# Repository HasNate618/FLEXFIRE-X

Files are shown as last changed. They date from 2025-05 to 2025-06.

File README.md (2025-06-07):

# ⚡ FLEXFIRE-X: EMG-Controlled Cyberware-Inspired Projectile System

A wearable, servo-powered arm attachment that extends and fires a spring-loaded projectile using EMG muscle signals—built to mimic the immersive cyberware experience of *Cyberpunk 2077*.

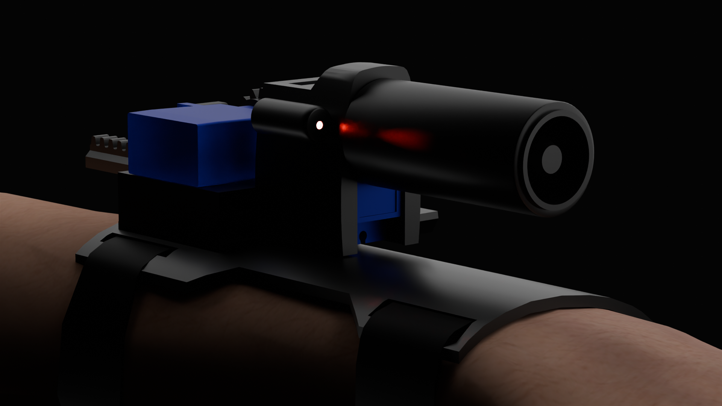
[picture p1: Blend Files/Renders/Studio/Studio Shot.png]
Studio Render


&nbsp;

## 🚀 Overview

**FLEXFIRE-X** is a bio-integrated device that mounts on the user's forearm and responds to intuitive muscle movements:

- ⬇️ **Wrist rotation** (palm down) → **Barrel extends**
- 💪 **Forearm flexion** → **Projectile fires**

This project explores how EMG signals can control physical actuators to feel like a seamless extension of the human body.

Demo Animation

&nbsp;

## 🎥 Video Demo

Watch FLEXFIRE-X in action:  
Watch the demo (https://youtube.com/shorts/VqzTay1VbeE)

> A quick demonstration of EMG-based extension and firing using wrist and forearm movements.

&nbsp;

## 🧠 Concept & Inspiration

Inspired by the **Projectile Launch System** from *Cyberpunk 2077*, this prototype brings sci-fi to life with:

- EMG-based gesture control
- A concealed-to-exposed transformation mechanism
- Arduino-powered spring-loaded projectile launch

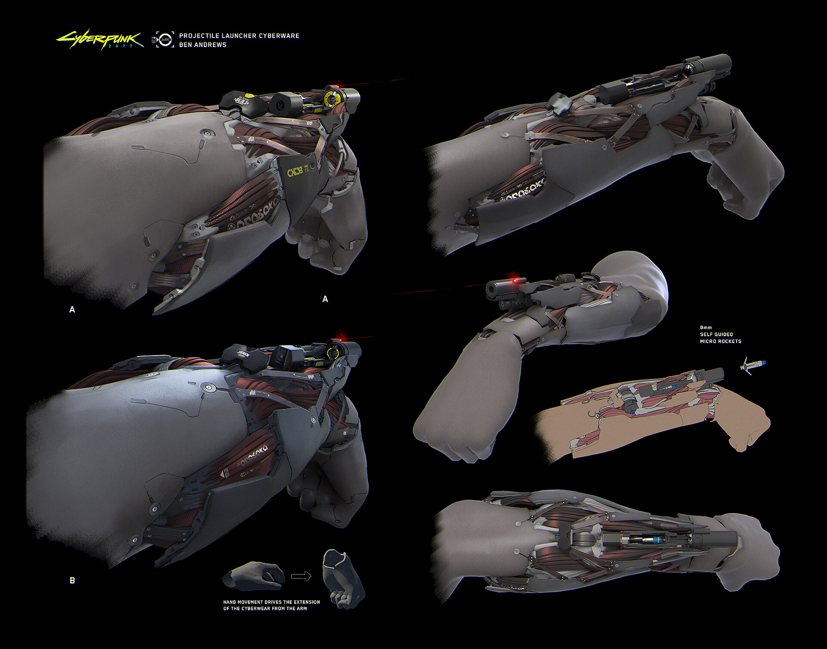
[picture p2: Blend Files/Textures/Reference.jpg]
Concept Art Reference

**Art by Ben Andrews on [ArtStation](https://www.artstation.com/artwork/WKqEVD)*

&nbsp;

## 💪 EMG Signal Detection
- Electrodes placed over the *flexor carpi radialis* muscle on the forearm help detect proper movement of the wrist and forearm flexion.
- Muscle signals are filtered via moving average to produce more stable results.
- Three flexion states are used for control based on the sensor readings:
  - **Low Flexion (<50)** → Barrel stays retracted
  - **Medium Flexion (>50)** → Barrel extends
  - **High Flexion (>500)** → Projectile is launched

&nbsp;

## 🔧 3D Design

The FLEXFIRE-X uses a total of nine 3D printed components that were designed in Blender and printed in PLA. 

An exploded view of the device shows the layout of each part:

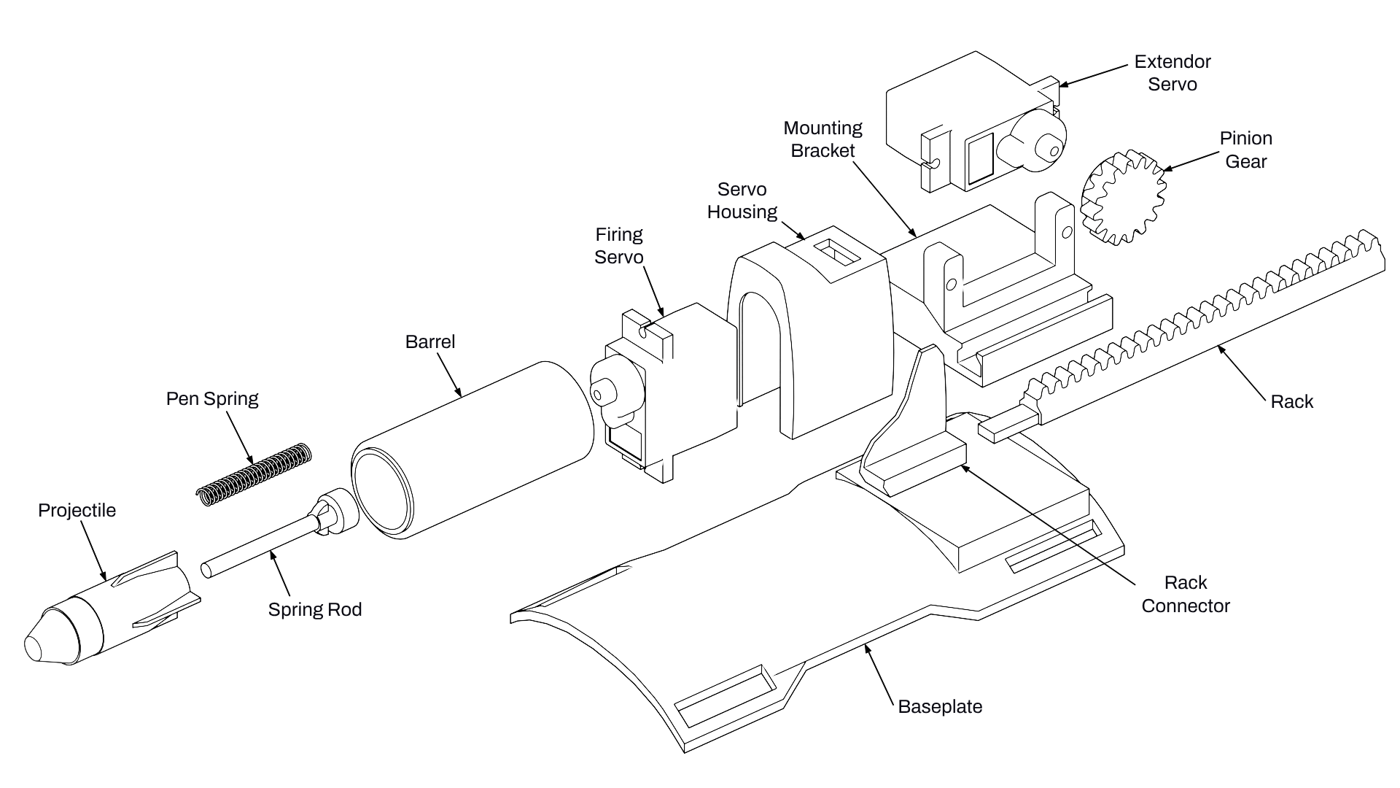
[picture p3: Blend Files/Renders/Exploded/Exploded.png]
Exploded View

**The Mounting Bracket, Rack and Pinion Gear were modified from [potentprintables](https://www.thingiverse.com/thing:3170748) design on Thingiverse*

&nbsp;

## 🔫 Launching Mechanism

The projectile is launched using a spring-loaded barrel system controlled by a servo-actuated locking mechanism. Here's how it works:

1. The rocket is inserted into the barrel, with its fins aligning with internal grooves to ensure proper orientation and constrain its rotation.
2. As the rocket is pushed in, the spring compresses, storing potential energy.
3. A servo rotates a locking rod, holding the rocket securely in place under spring tension.
4. When the servo rotates back to its original position, the lock is disengaged, allowing the spring to decompress and launch the rocket forward.
5. **Note:** To increase launch force, multiple springs can be nested concentrically within the barrel.

<p align="center">
  Launcher Demo
</p>

&nbsp;

## ⚙️ Hardware & Components

The following components were used to build the device and circuit

| Component | Purpose |
|---|---|
| Arduino Nano RP2040 Connect | Main microcontroller |
| EMG Sensor | Muscle signal detection |
| SG90 Servo Motor | Projectile launch trigger |
| Continuous Servo | Barrel extension/retraction |
| Pen Springs | Launches the projectile |
| 5V Red Laser | Aim assistance |
| 9V Batteries | On-body power management |

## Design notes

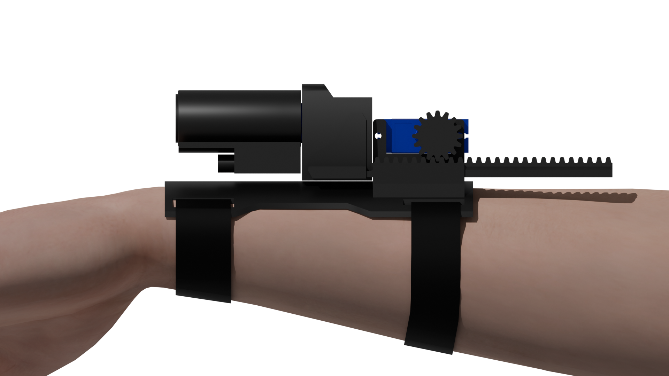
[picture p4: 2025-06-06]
Blend Files/Renders/Studio/Side_Transparent.png

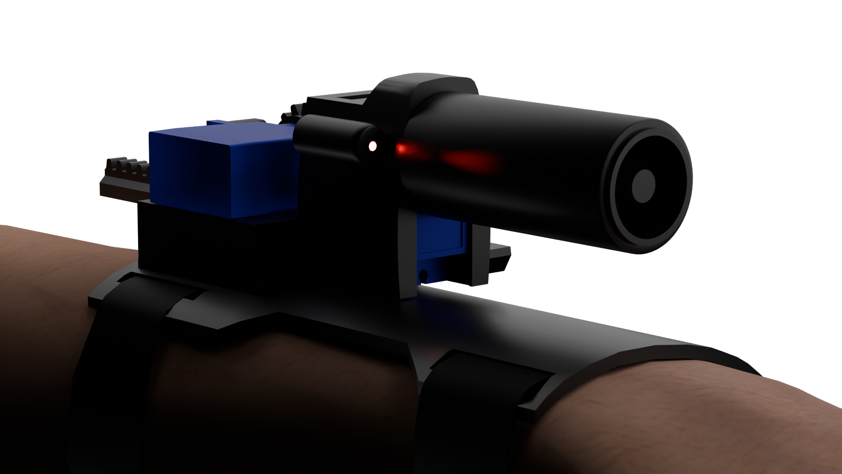
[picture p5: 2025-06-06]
Blend Files/Renders/Studio/Studio_Transparent.png

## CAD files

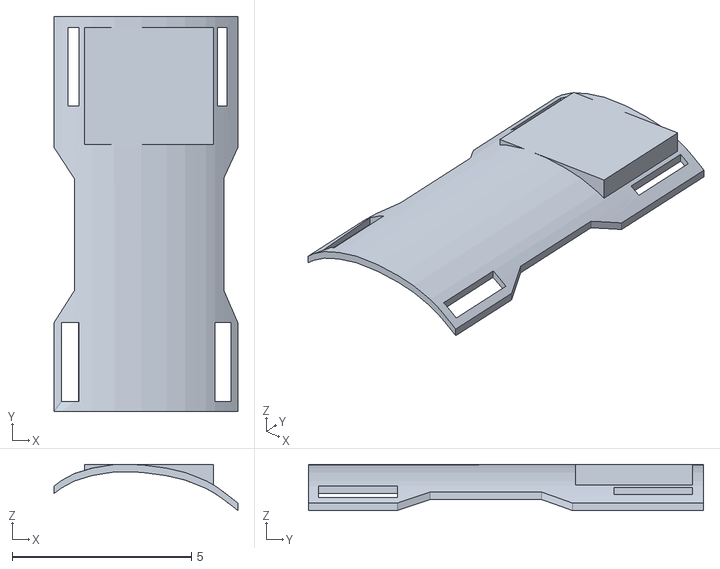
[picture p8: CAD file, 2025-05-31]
3D Print Files/Baseplate.stl
5.12 x 11.0 x 1.29

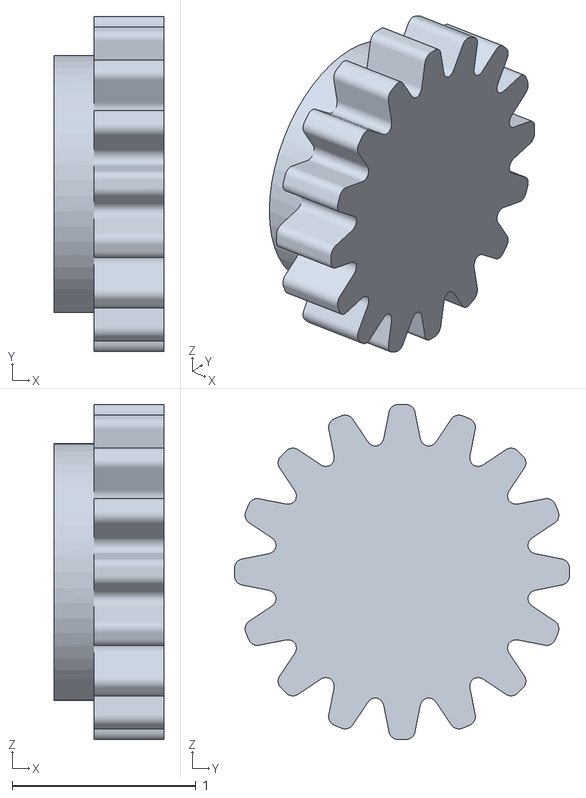
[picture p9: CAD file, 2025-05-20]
3D Print Files/Pinion Gear.stl
0.597 x 1.82 x 1.82

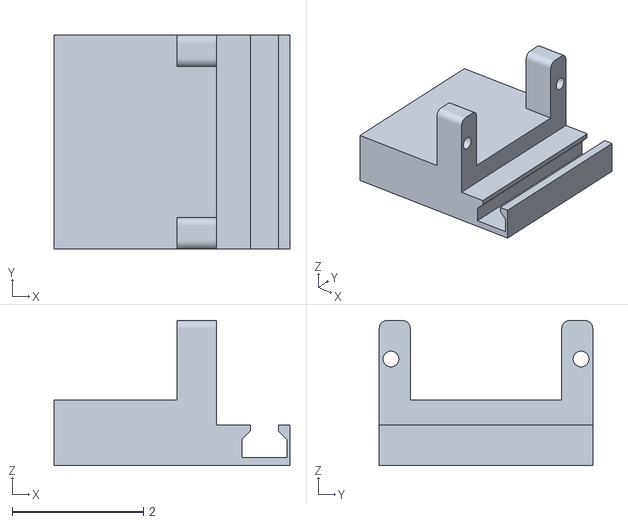
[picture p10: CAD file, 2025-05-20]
3D Print Files/Rack.stl
3.60 x 3.26 x 2.22

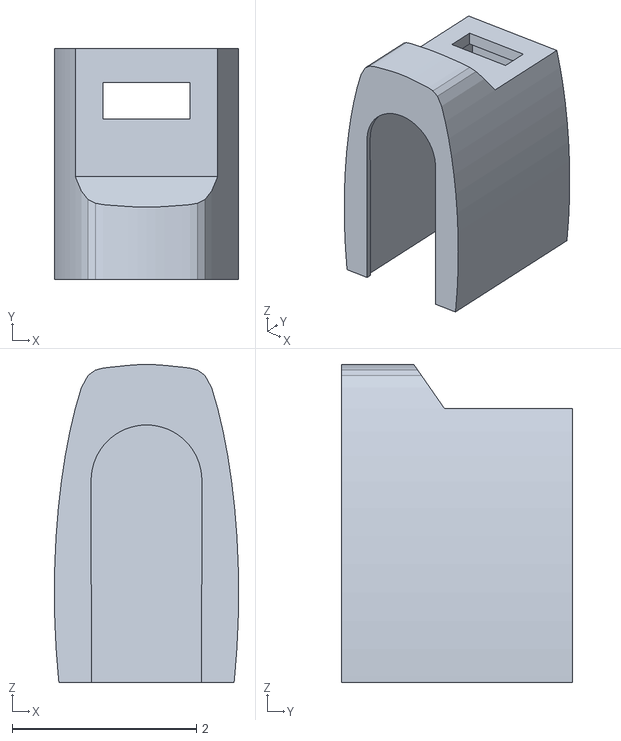
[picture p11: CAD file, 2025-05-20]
3D Print Files/Servo Housing.stl
2.00 x 2.50 x 3.45

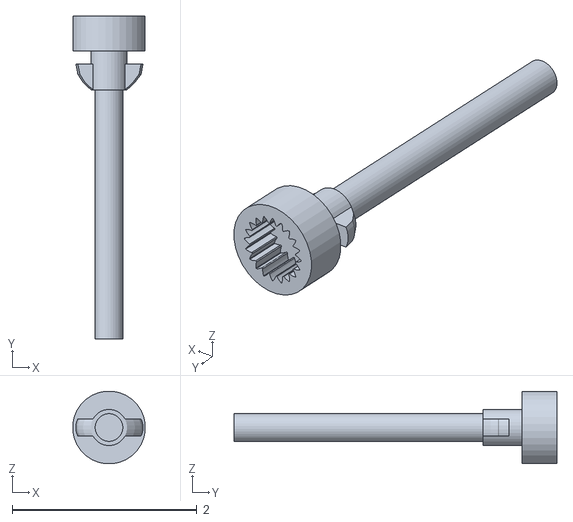
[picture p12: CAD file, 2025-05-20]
3D Print Files/Spring Rod.stl
0.785 x 3.50 x 0.785

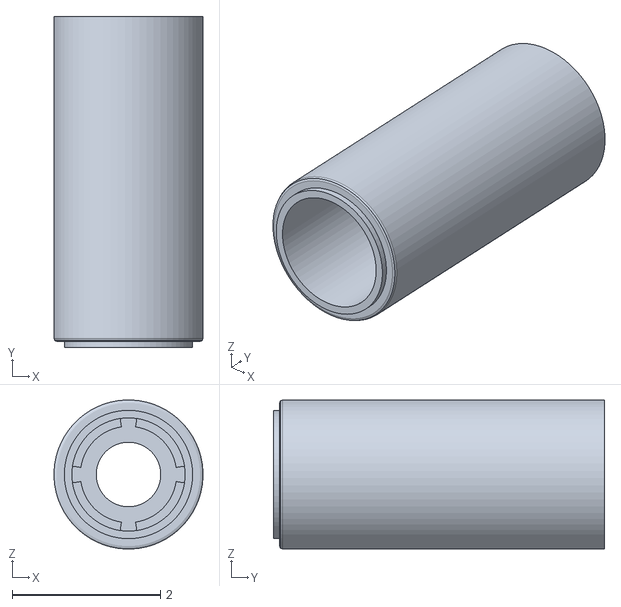
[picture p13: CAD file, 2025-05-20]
3D Print Files/Barrel.stl
2.01 x 4.48 x 2.01

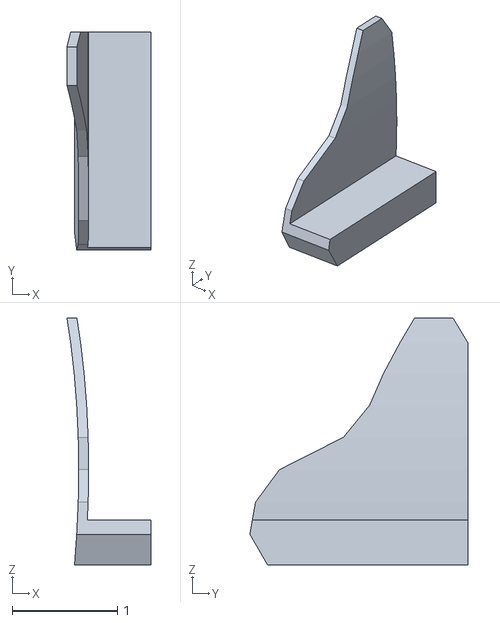
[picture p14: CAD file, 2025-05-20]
3D Print Files/Rack Connector.stl
0.8 x 2.08 x 2.35

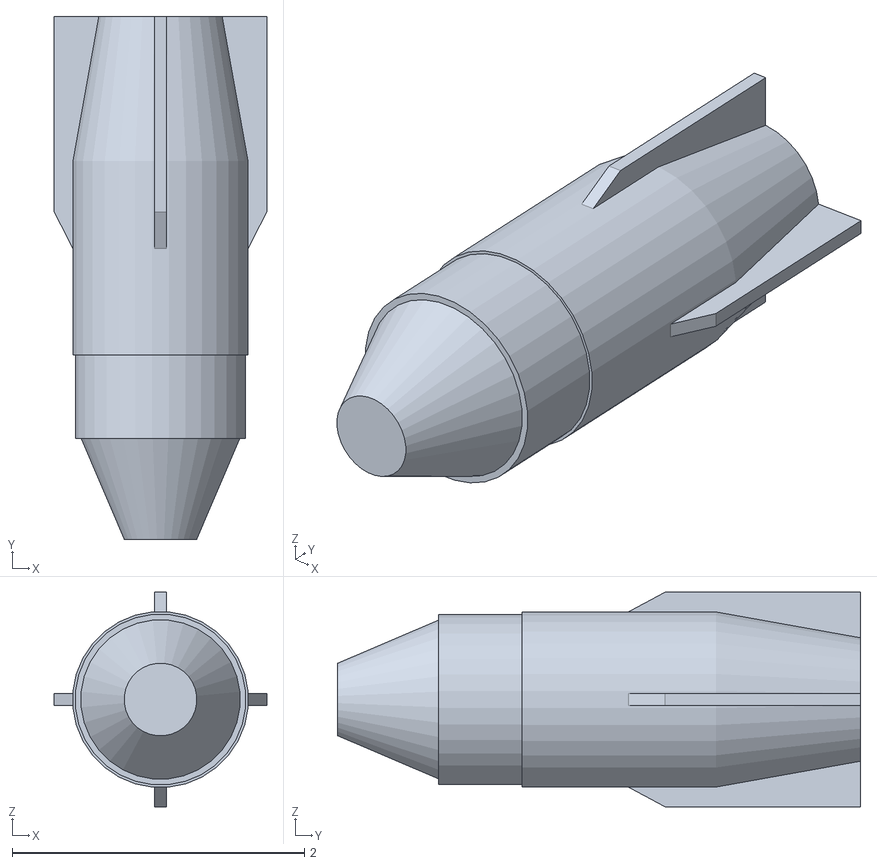
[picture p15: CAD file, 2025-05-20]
3D Print Files/Projectile.stl
1.45 x 3.58 x 1.47

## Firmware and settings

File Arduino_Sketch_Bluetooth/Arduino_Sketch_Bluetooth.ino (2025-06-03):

#include <ArduinoBLE.h>
#include <Servo.h>

Servo servo1; // Rotational: toggles 0 ↔ 90
Servo servo2; // Continuous: extend() ↔ retract()

int servo1Pin = 2;
int servo2Pin = 3;

bool state1 = false; // servo1: false = 0, true = 90
bool state2 = false;  // servo2: true = extended, false = retracted

bool lastButton1 = false;
bool lastButton2 = false;

BLEDevice peripheral;
BLECharacteristic inputCharacteristic;

const int rotationTime = 400; // ms to spin 360° for servo2

void setup() {
  Serial.begin(9600);

  servo1.attach(servo1Pin);
  servo2.attach(servo2Pin);

  servo1.write(0);   // initial angle
  servo2.write(96);  // stop signal for continuous servo

  delay(200);

  if (!BLE.begin()) {
    Serial.println("Starting BLE failed!");
    while (1);
  }

  BLE.scan(); // Start scanning

  Serial.println("Scanning for peripheral...");
}

void loop() {
  // Try to connect to peripheral if not connected
  if (!peripheral || !peripheral.connected()) {
    peripheral = BLE.available();

    if (peripheral && peripheral.localName() == "Hand Peripheral Device") {
      BLE.stopScan();
      Serial.println("Connecting to peripheral...");

      if (peripheral.connect()) {
        Serial.println("Connected!");

        if (peripheral.discoverAttributes()) {
          inputCharacteristic = peripheral.characteristic("d66f7f33-24ae-4dc0-bf22-b9c54f92cdd0");

          if (!inputCharacteristic) {
            Serial.println("Characteristic not found.");
            peripheral.disconnect();
            BLE.scan();
            return;
          }

          inputCharacteristic.subscribe();
        }
      } else {
        Serial.println("Connection failed.");
        BLE.scan();
      }
    }
    return;
  }

  // Handle data from peripheral
  if (inputCharacteristic.valueUpdated()) {
    String value = (const char*)inputCharacteristic.value();
    //Serial.println("Received: " + value);

    // Parse buttons from value
    int lastComma = value.lastIndexOf(',');
    int secondLastComma = value.lastIndexOf(',', lastComma - 1);
    int b1 = value.substring(secondLastComma + 1, lastComma).toInt();
    int b2 = value.substring(lastComma + 1).toInt();

    bool currentButton1 = b1 == 1;
    bool currentButton2 = b2 == 1;

    // === Servo 1 (Rotational) ===
    if (currentButton1 && !lastButton1) {
      state1 = !state1;
      int angle = state1 ? 90 : 0;
      servo1.write(angle);
      Serial.print("Servo1 angle: ");
      Serial.println(angle);
    }

    // === Servo 2 (Continuous Rotation) ===
    if (currentButton2 && !lastButton2) {
      state2 = !state2;
      if (state2) {
        extend();
      } else {
        retract();
      }
    }
    else {
      int potValue = analogRead(A0);
      int servoSpeed = map(potValue, 0, 1023, 82, 108);
      if (abs(servoSpeed - 96) < 6) {
        servoSpeed = 96; // Stay still if within deadzone
      }
      servo2.write(servoSpeed);
    }

    lastButton1 = currentButton1;
    lastButton2 = currentButton2;
  }

  delay(70);
}

// === Servo 2 Control ===

void extend() {
  servo2.write(0); // Full speed clockwise
  Serial.println("Extending...");
  delay(rotationTime);  // Calibrated
  servo2.write(96); // Stop
}

void retract() {
  servo2.write(180); // Full speed counter-clockwise
  Serial.println("Retracting...");
  delay(rotationTime-5);
  servo2.write(96); // Stop
}

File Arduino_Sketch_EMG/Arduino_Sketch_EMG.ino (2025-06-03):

#include <Servo.h>

Servo servo1; // Rotational: toggles 0 ↔ 90
Servo servo2; // Continuous: extend() ↔ retract()

int servo1Pin = 2;
int servo2Pin = 3;

bool state1 = false; // servo1: false = 0, true = 90
bool state2 = false;  // servo2: true = extended, false = retracted

const int rotationTime = 400; // ms to spin 360° for servo2

const int emgPin = A1;
const int numSamples = 8;
int emgReadings[numSamples];
int emgIndex = 0;
long total = 0;

void setup() {
  Serial.begin(9600);

  servo1.attach(servo1Pin);
  servo2.attach(servo2Pin);

  servo1.write(0);   // initial angle
  servo2.write(96);  // stop signal for continuous servo
}

void loop() {
  // === EMG Moving Average ===
  total -= emgReadings[emgIndex];
  emgReadings[emgIndex] = analogRead(emgPin);
  total += emgReadings[emgIndex];
  emgIndex = (emgIndex + 1) % numSamples;
  int emgAvg = total / numSamples;
  Serial.println(emgAvg);

  // EMG-based control for servo1 (toggle) and servo2 (extend/retract)
  if (emgAvg > 60) {
    int emgValue = analogRead(emgPin);  // Read raw EMG again for spike detection

    // Extend servo2 if not already extended
    if (!state2) {
      extend();
      state2 = true;
    }

    // Toggle servo1 if spike is detected
    if (emgValue > 500) {
      state1 = !state1;
      int angle = state1 ? 90 : 0;
      servo1.write(angle);
      Serial.print("Servo1 toggled by EMG spike. New angle: ");
      Serial.println(angle);
      delay(300); // Debounce delay
    }
  } else {
    // Retract servo2 if not already retracted
    if (state2) {
      retract();
      state2 = false;
    }
  }

  int potValue = analogRead(A0);
  int servoSpeed = map(potValue, 0, 1023, 82, 108);
  if (abs(servoSpeed - 96) < 6) {
    servoSpeed = 96; // Stay still if within deadzone
  }
  servo2.write(servoSpeed);

  delay(70);
}

// === Servo 2 Control ===

void extend() {
  servo2.write(0); // Full speed clockwise
  Serial.println("Extending...");
  delay(rotationTime-5);  // Calibrated
  servo2.write(96); // Stop
}

void retract() {
  servo2.write(180); // Full speed counter-clockwise
  Serial.println("Retracting...");
  delay(rotationTime);
  servo2.write(96); // Stop
}

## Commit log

2025-05-31 update for cont servo
    [Baseplate.stl]
2025-06-06 create documentation
    [Pusher Connector.stl, Pusher.stl, Rack Connector.stl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]
